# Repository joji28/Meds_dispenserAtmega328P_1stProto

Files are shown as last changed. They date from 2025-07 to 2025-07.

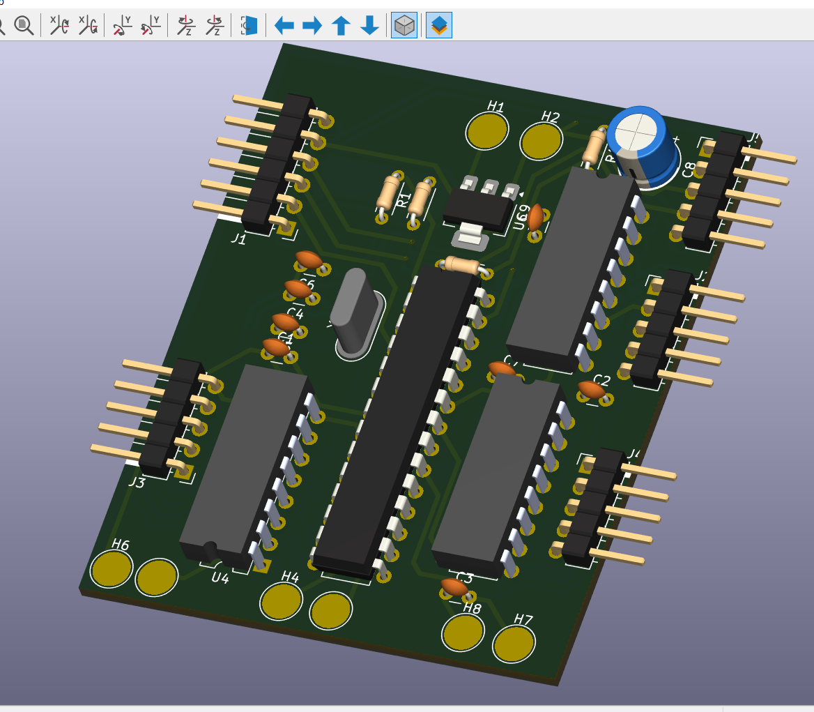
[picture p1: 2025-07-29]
atmega_3d_pcb.png

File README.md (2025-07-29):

# Meds_dispenserAtmega328P_1stProto
Smart Medicine Dispenser
Project Description
This automated medicine dispenser is designed to release medication at three scheduled times (morning, afternoon, and dinner) using stepper motors. The first prototype was built around an ATmega328P microcontroller (pulled from an Arduino UNO) and programmed using Atmel Studio 7.0 with an AVR 8051 USB ISP programmer.

Key Features
Time-Based Dispensing: Takes user input via Bluetooth (HC-05) to set the current time and three medication schedules.
Real-Time Tracking: Uses an RTC (DS3231) for accurate timekeeping.
Visual Feedback: Displays time and alerts on a 0.94" OLED screen.
Motor Control: Three 28BYJ-5V stepper motors (driven by ULN2003) rotate 45° to dispense pills when scheduled.
Power Management: A 12V input is stepped down to 5V using an AMS1117 regulator for safe operation.

How It Works
User Input Setup
The user sets the current time and three medication times via Bluetooth (HC-05).
The RTC (DS3231) is updated, and the schedule is displayed on the OLED for verification.

Automated Dispensing
The system continuously checks the RTC.
When the current time matches a scheduled time, the corresponding stepper motor rotates 45°, dispensing the medicine.
A confirmation message (e.g., "Afternoon medicine dispensed") appears on the OLED.

Daily Reset
The system loops indefinitely, dispensing medication at the same times every day.

Hardware Components
ATmega328P (from Arduino UNO) -> Main microcontroller (11.0592 MHz oscillator)
HC-05 Bluetooth Module ->	Wireless input for time settings
DS3231 RTC	-> Keeps accurate time for scheduling
0.94" OLED Display	-> Shows time, settings, and dispensing alerts
28BYJ-5V Stepper Motors (x3)	-> Rotate to dispense pills
ULN2003 Motor Drivers (x3)	-> Control stepper motors
AMS1117 5V Regulator ->	Converts 12V input to 5V for components
Rocker Switch ->	Power control

-I've also attached the schematics and pcbs(2 layers) design in kicad along with a video of testing components pls feel free to refer those.

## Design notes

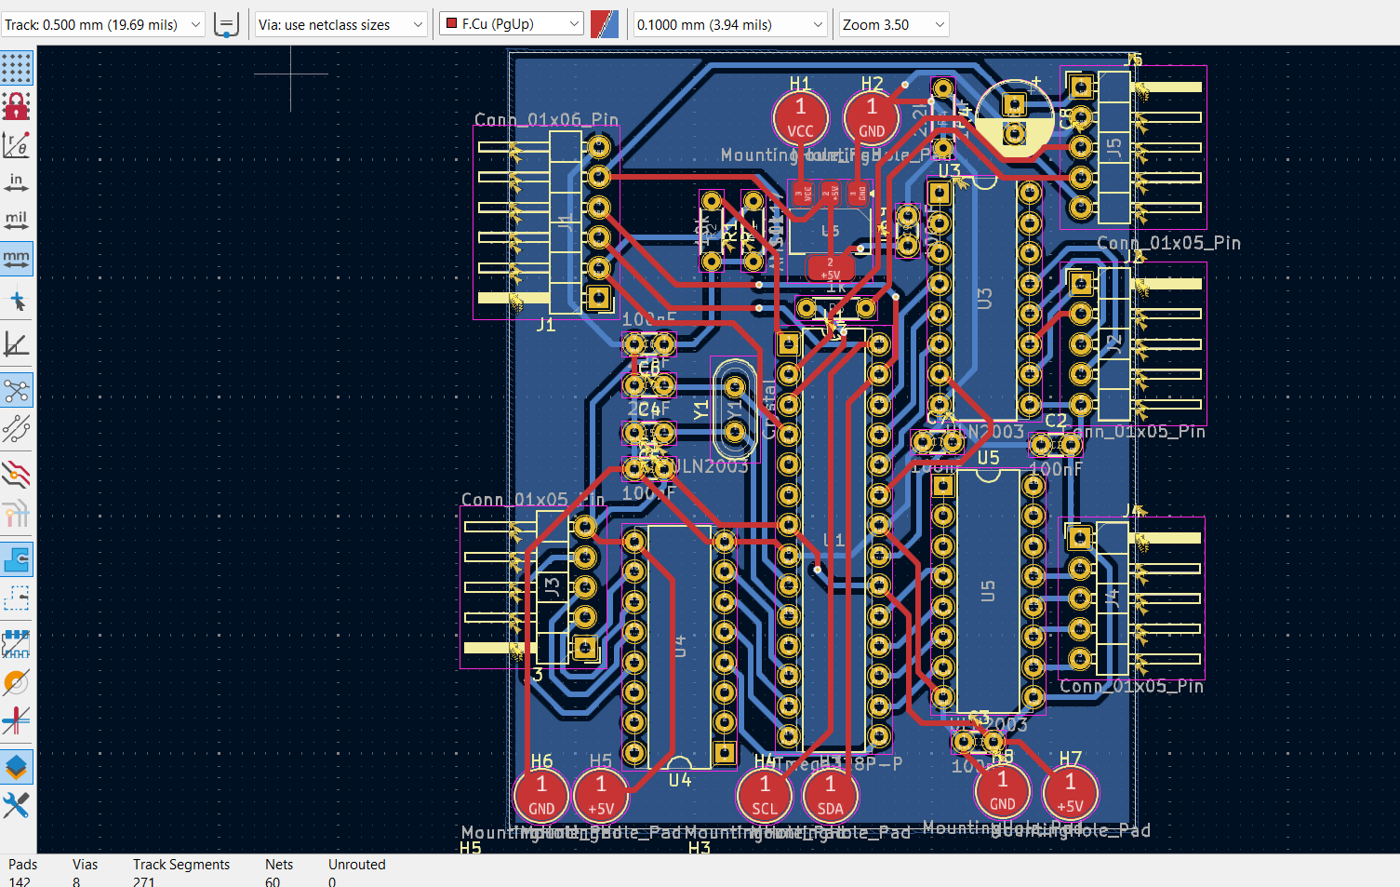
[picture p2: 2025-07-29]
atmega_pcb.png

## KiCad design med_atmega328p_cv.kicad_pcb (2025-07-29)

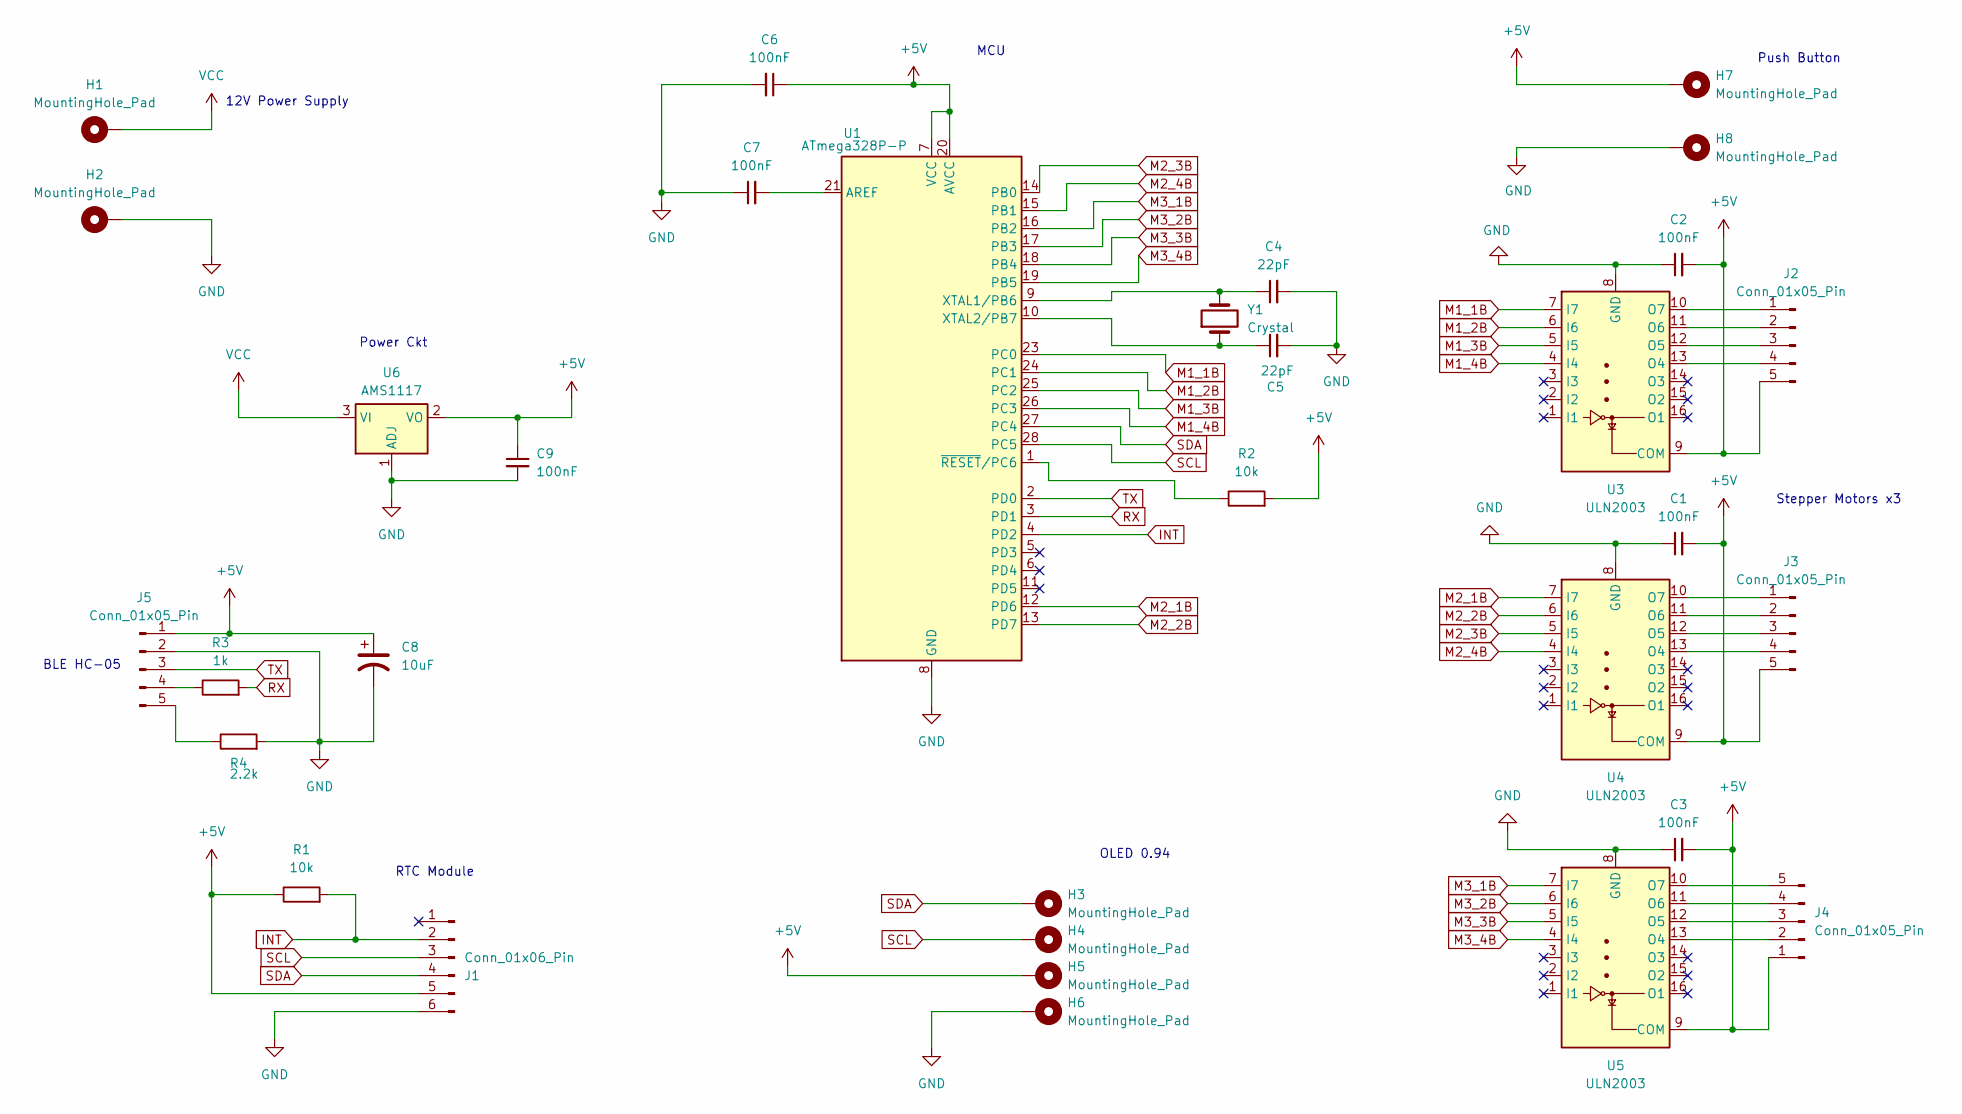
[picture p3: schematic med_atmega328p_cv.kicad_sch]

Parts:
C1, C2, C3, C6, C7, C9: 100nF; C_Disc_D3.0mm_W1.6mm_P2.50mm
C4, C5: 22pF; C_Disc_D3.0mm_W1.6mm_P2.50mm
C8: 10uF; CP_Radial_D6.3mm_P2.50mm
H1, H2, H3, H4, H5, H6, H7, H8: MountingHole_Pad; TestPoint_Pad_D4.0mm
J1: Conn_01x06_Pin; PinHeader_1x06_P2.54mm_Horizontal
J2, J3, J4, J5: Conn_01x05_Pin; PinHeader_1x05_P2.54mm_Horizontal
R1, R2: 10k; R_Axial_DIN0204_L3.6mm_D1.6mm_P5.08mm_Horizontal
R3: 1k; R_Axial_DIN0204_L3.6mm_D1.6mm_P5.08mm_Horizontal
R4: 2.2k; R_Axial_DIN0204_L3.6mm_D1.6mm_P5.08mm_Horizontal
U1: ATmega328P-P; DIP-28_W7.62mm
U3, U4, U5: ULN2003; CERDIP-16_W7.62mm_SideBrazed
U6: AMS1117; SOT-223-3_TabPin2
Y1: Crystal; Crystal_HC52-6mm_Vertical

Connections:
+5V: C1.2, C2.2, C3.2, C6.1, C8.1, C9.1, H5.1, H7.1, J1.5, J2.5, J3.5, J4.1, J5.1, R1.1, R2.2, U1.7 (VCC), U1.20 (AVCC), U3.9 (COM), U4.9 (COM), U5.9 (COM), U6.2 (VO)
GND: C1.1, C2.1, C3.1, C4.2, C5.2, C6.2, C7.1, C8.2, C9.2, H2.1, H6.1, H8.1, J1.6, J5.2, R4.2, U1.8 (GND), U1.22 (GND), U3.8 (GND), U4.8 (GND), U5.8 (GND), U6.1 (ADJ)
INT: J1.2, R1.2, U1.4 (PD2)
M1_1B: U1.23 (PC0), U3.7 (I7)
M1_2B: U1.24 (PC1), U3.6 (I6)
M1_3B: U1.25 (PC2), U3.5 (I5)
M1_4B: U1.26 (PC3), U3.4 (I4)
M2_1B: U1.12 (PD6), U4.7 (I7)
M2_2B: U1.13 (PD7), U4.6 (I6)
M2_3B: U1.14 (PB0), U4.5 (I5)
M2_4B: U1.15 (PB1), U4.4 (I4)
M3_1B: U1.16 (PB2), U5.7 (I7)
M3_2B: U1.17 (PB3), U5.6 (I6)
M3_3B: U1.18 (PB4), U5.5 (I5)
M3_4B: U1.19 (PB5), U5.4 (I4)
unnamed: J2.1, U3.10 (O7)
unnamed: J2.2, U3.11 (O6)
unnamed: J2.3, U3.12 (O5)
unnamed: J2.4, U3.13 (O4)
unnamed: J3.1, U4.10 (O7)
unnamed: J3.2, U4.11 (O6)
unnamed: J3.3, U4.12 (O5)
unnamed: J3.4, U4.13 (O4)
unnamed: J4.2, U5.13 (O4)
unnamed: J4.3, U5.12 (O5)
unnamed: J4.4, U5.11 (O6)
unnamed: J4.5, U5.10 (O7)
unnamed: J5.4, R3.1
unnamed: J5.5, R4.1
unnamed: C7.2, U1.21 (AREF)
unnamed: C4.1, U1.9 (XTAL1/PB6), Y1.2
unnamed: C5.1, U1.10 (XTAL2/PB7), Y1.1
unnamed: R2.1, U1.1 (~RESET/PC6)
RX: R3.2, U1.3 (PD1)
SCL: H4.1, J1.3, U1.28 (PC5)
SDA: H3.1, J1.4, U1.27 (PC4)
TX: J5.3, U1.2 (PD0)
VCC: H1.1, U6.3 (VI)

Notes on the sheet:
Push Button
12V Power Supply
RTC Module
MCU
Power Ckt
OLED 0.94
Stepper Motors x3
BLE HC-05

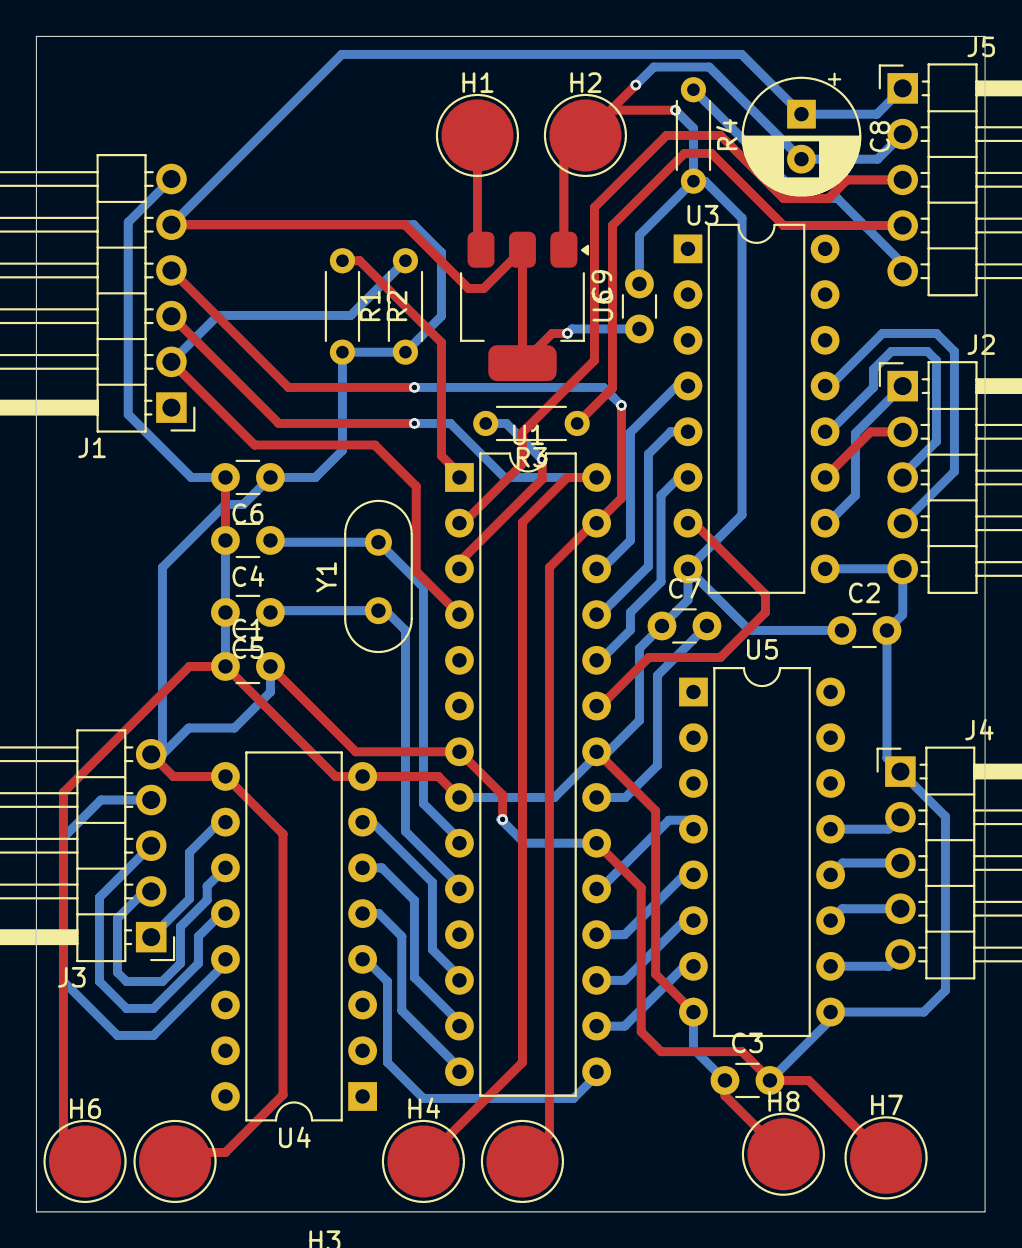
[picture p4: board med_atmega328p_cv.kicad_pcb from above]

Board: 2 copper layers, 52.7 x 65.3 mm, 32 parts (0 on the bottom side), 38 nets.

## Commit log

2025-07-29 Add files via upload
    font.h was the library that helped me print ascii values like alphabets and numbers on my oled display cuz you need to enter ascii values of each alphabets for the atmega 8bit to process it and displ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
2025-07-29 Add files via upload
    a small testing video where the stepper moves 45 degrees when current time reaches the target time
